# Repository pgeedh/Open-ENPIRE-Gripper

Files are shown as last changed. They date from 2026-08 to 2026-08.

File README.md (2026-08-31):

# Open-ENPIRE-Gripper-NVIDIA

<div align="center">






### Universal Compliant Gripper (UCG) Adapters for Robot Learning & Physical AI

<br>

<table align="center" border="0">
  <tr>
    <th align="center" width="50%">NVIDIA GEAR ENPIRE Research Video</th>
    <th align="center" width="50%">Robotiq Hand-E Physical Adapter</th>
  </tr>
  <tr>
    <td align="center" valign="top">
      <a href="https://research.nvidia.com/labs/gear/enpire/">
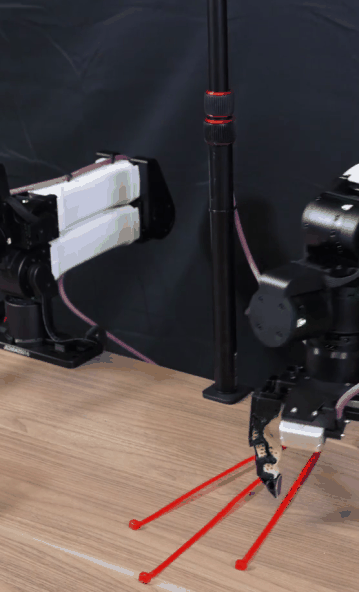
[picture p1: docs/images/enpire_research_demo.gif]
NVIDIA GEAR ENPIRE Autonomous Manipulation
        
      </a>
    </td>
    <td align="center" valign="top">
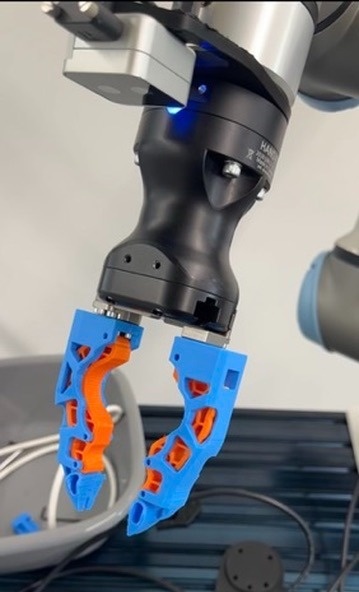
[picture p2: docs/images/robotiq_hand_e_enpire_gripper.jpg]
Robotiq Hand-E ENPIRE Gripper
      
    </td>
  </tr>
</table>

</div>

---

## Purpose & Mission

### Why This Project Exists
In physical AI manipulation research, grasping reliability is fundamentally determined by hardware contact mechanics, including surface friction, passive compliance, and tactile geometry. When NVIDIA's GEAR lab published **ENPIRE** (*Agentic Robot Policy Self-Improvement in the Real World*), co-led by **Dr. Jim Fan** ([@DrJimFan](https://twitter.com/DrJimFan)) and **Dr. Yuke Zhu**, the physical robot achieved remarkable grasping reliability using a custom-engineered 3D-printable finger designed by **Wenli Xiao** (CMU & NVIDIA GEAR) for the **I2RT YAM** robotic arm.

<table align="center" border="0">
  <tr>
    <th align="center" width="50%">Original NVIDIA ENPIRE (I2RT YAM)</th>
    <th align="center" width="50%">Generalist AI (Bimanual Manipulation)</th>
  </tr>
  <tr>
    <td align="center" valign="top">
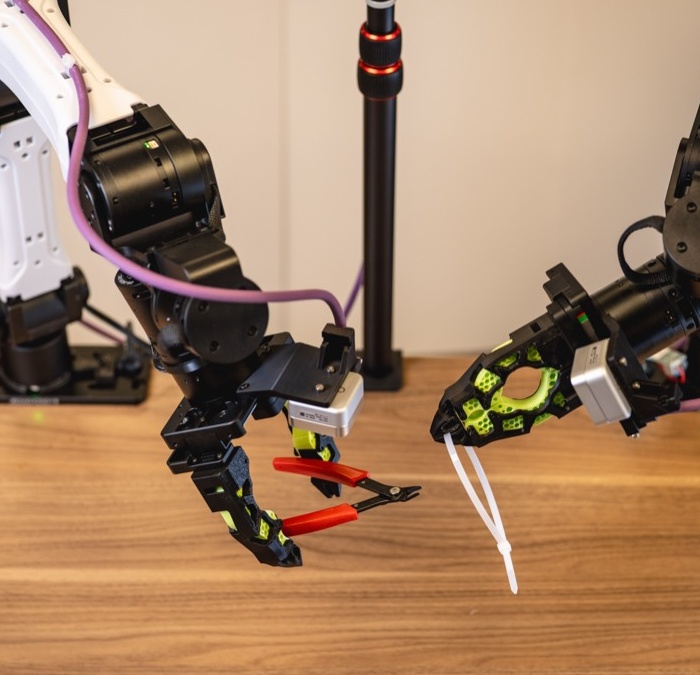
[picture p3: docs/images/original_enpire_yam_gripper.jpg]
Original NVIDIA ENPIRE I2RT YAM Gripper
      
    </td>
    <td align="center" valign="top">
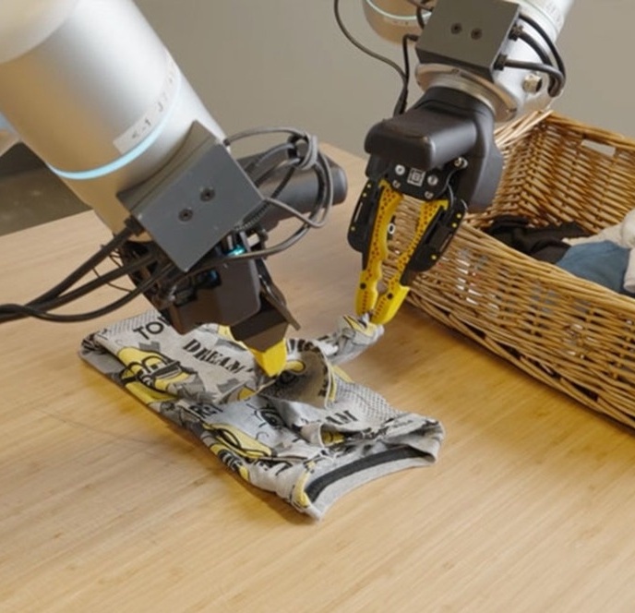
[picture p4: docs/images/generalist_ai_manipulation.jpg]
Generalist AI Bimanual Manipulation
      
    </td>
  </tr>
</table>

However, the I2RT YAM is a specialized research arm that very few universities, startups, independent makers, or robotics labs own.

### The Rise of Universal Compliant Grippers (UCG) in Physical AI
Across the frontier robotics industry, leading physical AI companies and research teams (including **[Generalist AI](https://generalistai.com/blog/research-preview)**, **[Physical Intelligence (Pi)](https://twitter.com/Physical_Int)**, **[Figure AI](https://twitter.com/Figure_robot)**, **[1X Technologies](https://twitter.com/1x_tech)**, **[Skild AI](https://twitter.com/Skild_AI)**, **[Tesla Optimus](https://twitter.com/Tesla_Optimus)**, **[AgileX Robotics](https://twitter.com/AgilexRobotics)**, and **[Toyota Research Institute (TRI)](https://www.tri.global/)**) are converging on a shared thesis: **deploying general-purpose physical AI requires versatile, compliant, high-friction parallel fingertips that can handle diverse, delicate, and high-force interactions without tool-changers**.

We refer to this design paradigm as the **Universal Compliant Gripper (UCG)**.  
*(Note: UCG is not an official industry acronym, but rather our term to describe this class of cross-platform, passively compliant, high-friction parallel hardware).*

### Empowering Modern Robot Learning: $\pi_0$, GR00T, Diffusion Policy, & ACT
State-of-the-art robot learning policies and foundation models require hardware that can absorb physical uncertainty:
* **$\pi_0$ (Pi-Zero by Physical Intelligence)**: Flow-matching / diffusion generalist physical AI model requiring robust non-slip tactile dynamics across complex multi-task domains.
* **GR00T (NVIDIA Generalist Robot 00T)**: Multimodal foundation model driving humanoid and bimanual dexterous manipulation.
* **Diffusion Policy (DP / Chi et al.)**: Visuomotor action diffusion executing high-frequency continuous action trajectories.
* **ACT (Action Chunking with Transformers / Zhao et al.)**: High-frequency bimanual imitation learning powering ALOHA and tabletop learning rigs.
* **OpenVLA, Octo, RT-1 & RT-2**: Vision-Language-Action models mapping tokens to spatial end-effector displacements.

When training these policies, robots encounter an expansive distribution of physical objects: folding delicate fabrics, tensioning flexible zip-ties, sorting thin fasteners, handling micro-pins, and seating rigid PCBs.

The core aim of this project is to deliver a **Universal Compliant Gripper (UCG) finger architecture versatile enough to master this broad spectrum of manipulation tasks** to **enhance the capabilities of existing robot hardware** and **democratize frontier physical AI for everyone**.

In the open-source community, researchers and builders train policies across diverse robotic arms:
* **Robotiq Hand-E**: Precision electric parallel gripper for industrial and research cobots.
* **Robotiq 2F-85 & 2F-140**: High-payload adaptive parallel grippers for Universal Robots, Kinova, and AUBO.
* **Open Arm**: Accessible open-source robotics platform.
* **I2RT YAM**: Foundational research platform from NVIDIA GEAR ENPIRE.
* **ALOHA / Mobile ALOHA**: Stanford/Trossen bimanual imitation learning standard.
* **AgileX (Piper)**: Lightweight 6-DoF bimanual research arms.
* **Seeed Studio reBot**: Low-cost edge AI vision-language-action (VLA) testbed.
* **Franka Emika Panda / FR3**: 7-DoF contact-physics research standard.
* **ARX5**: Bimanual mobile manipulation arms.

### Mission: Democratizing Frontier Gripper Design
> **Hardware breakthroughs in robotics should not be locked to a single proprietary arm.**
> 
> The mission of **Open-ENPIRE-Gripper-NVIDIA** is to bridge the gap between frontier physical AI research and the global robotics community:
> 1. **Universal Accessibility**: Translate the proven high-friction, compliant contact profile into 3D-printable STL adapters for popular robot arms. All printable models can be found in the [`grippers-stl/`](grippers-stl/) folder.
> 2. **Physical AI for Everyone**: Enable anyone with a standard 3D printer to achieve frontier-grade contact mechanics on their existing robot without purchasing expensive custom end-effectors.
> 3. **Community-Driven Standardization**: Establish this geometry as an open-source standard across all parallel-jaw robotic grippers, starting with our physical adaptations for **Robotiq Hand-E**, **Robotiq 2F-140**, **Open Arm**, and **I2RT YAM**.

*Original MakerWorld Project: [Gripper Finger for Robot Arm](https://makerworld.com/en/models/2984746-gripper-finger-for-robot-arm) / [Profile #3349177](https://makerworld.com/en/models/2984746-gripper-finger-for-robot-arm#profileId-3349177) by Wenli Xiao.*

---

## 🎨 3D STL Model Visual Gallery

<table align="center" border="0">
  <tr>
    <th align="center" width="25%">Robotiq Hand-E UCG</th>
    <th align="center" width="25%">Robotiq 2F-140 UCG</th>
    <th align="center" width="25%">Open Arm UCG</th>
    <th align="center" width="25%">I2RT YAM Baseline</th>
  </tr>
  <tr>
    <td align="center" valign="top">
      <a href="grippers-stl/hand_e_stl/">
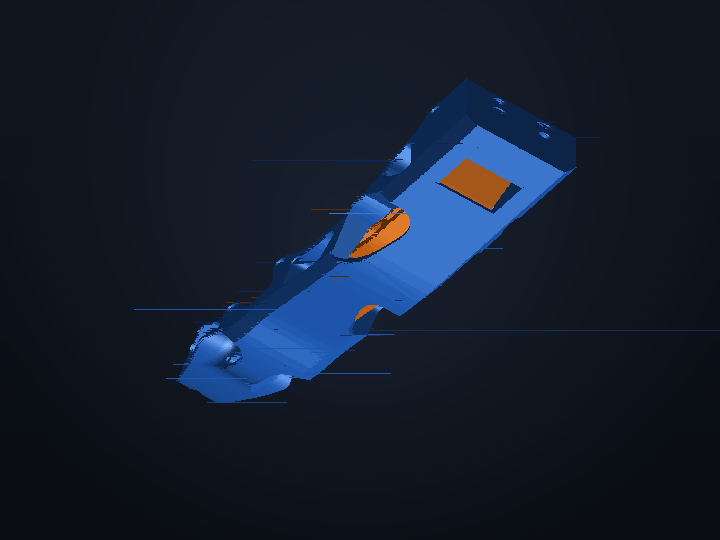
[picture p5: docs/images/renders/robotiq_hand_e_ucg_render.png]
Robotiq Hand-E UCG Render
        
      </a>
    </td>
    <td align="center" valign="top">
      <a href="grippers-stl/robotiq_2f85_2f140_stl/">
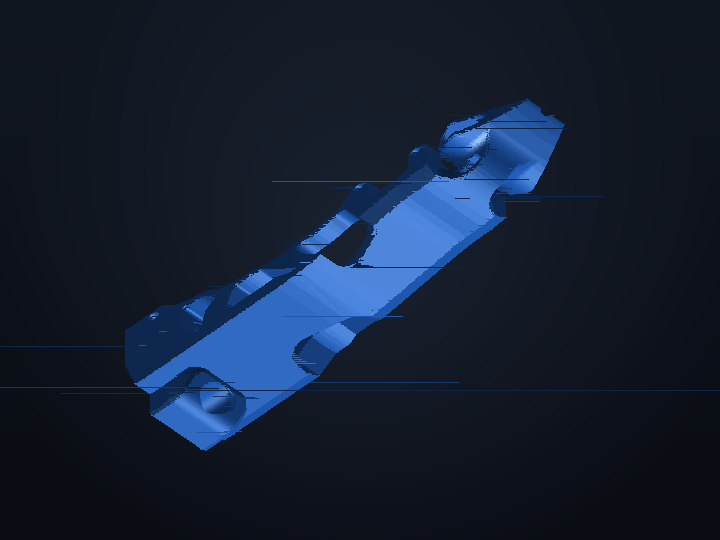
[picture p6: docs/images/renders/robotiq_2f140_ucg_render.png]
Robotiq 2F-140 UCG Render
        
      </a>
    </td>
    <td align="center" valign="top">
      <a href="grippers-stl/open_arm_stl/">
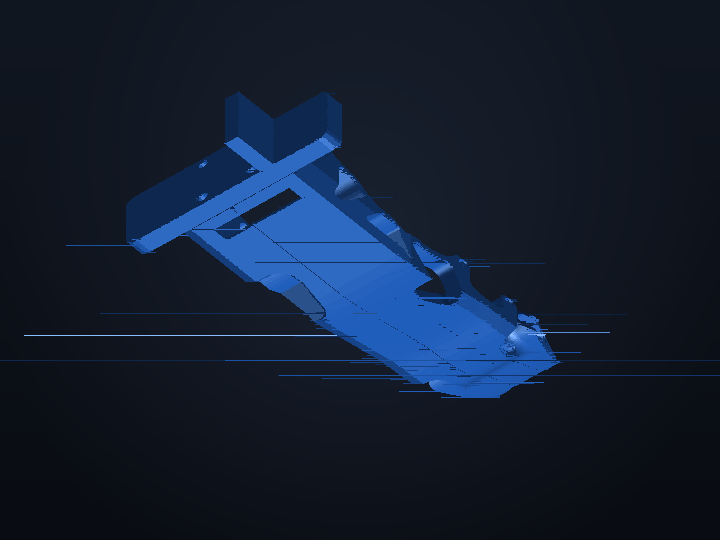
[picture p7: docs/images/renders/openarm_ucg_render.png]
Open Arm UCG Render
        
      </a>
    </td>
    <td align="center" valign="top">
      <a href="grippers-stl/enpire_i2rt_yam_stl/">
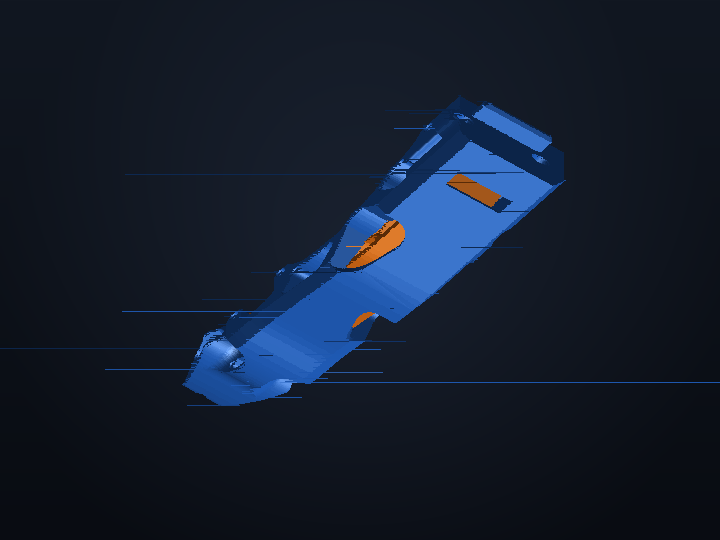
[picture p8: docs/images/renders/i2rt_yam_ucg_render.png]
I2RT YAM Baseline Render
        
      </a>
    </td>
  </tr>
  <tr>
    <td align="center"><strong>Robotiq Hand-E</strong></td>
    <td align="center"><strong>Robotiq 2F-140 / 2F-85</strong></td>
    <td align="center"><strong>Open Arm</strong></td>
    <td align="center"><strong>I2RT YAM Baseline</strong></td>
  </tr>
</table>

---

## Robot Compatibility Matrix

> 💡 **3D Printable Files**: All gripper STL models for supported robotic arms are available in the [`grippers-stl/`](grippers-stl/) directory.

| Robot Platform | Arm Type / Gripper Interface | Status | Target STL Folder |
| :--- | :--- | :---: | :--- |
| [**Robotiq Hand-E**](https://robotiq.com/products/hand-e-adaptive-robot-gripper) | Precision Electric Parallel Gripper | **Available** | [`grippers-stl/hand_e_stl/`](grippers-stl/hand_e_stl/) |
| [**Robotiq 2F-85 / 2F-140**](https://robotiq.com/products/2f85-140-adaptive-robot-gripper) | 2× M4 Bracket Mount (10 mm spacing) | **Available** | [`grippers-stl/robotiq_2f85_2f140_stl/`](grippers-stl/robotiq_2f85_2f140_stl/) |
| **Open Arm** | Modular Open-Source Parallel Mount | **Available** | [`grippers-stl/open_arm_stl/`](grippers-stl/open_arm_stl/) |
| **I2RT YAM** | Native Dual M3 Clamp (Wenli Xiao Baseline) | **Available** | [`grippers-stl/enpire_i2rt_yam_stl/`](grippers-stl/enpire_i2rt_yam_stl/) |
| **ALOHA / Mobile ALOHA** | ViperX Parallel Jaw Carriage | *In Progress* | [`grippers-stl/aloha_stl/`](grippers-stl/aloha_stl/) |
| **AgileX (Piper)** | Dual Pin + M3 Fastener Slider | *In Progress* | [`grippers-stl/agilex_stl/`](grippers-stl/agilex_stl/) |
| **Seeed Studio reBot** | AI Arm Parallel Gripper Slider | *In Progress* | [`grippers-stl/seeed_rebot_stl/`](grippers-stl/seeed_rebot_stl/) |
| **Franka Panda / FR3** | Quick-Mount Dovetail / M4 Slider | *In Progress* | [`grippers-stl/franka_panda_stl/`](grippers-stl/franka_panda_stl/) |
| **ARX5** | Direct Dual Lug M3 Pattern | *In Progress* | [`grippers-stl/arx5_stl/`](grippers-stl/arx5_stl/) |
| **ISO 9409-1 (UR / xArm)** | Universal Tool Flange Adapter Plates | *In Progress* | [`grippers-stl/iso_flange_adapters_stl/`](grippers-stl/iso_flange_adapters_stl/) |

*Status: Available (Production-ready STL models available) | In Progress (Community Contributions Welcome)*

---

## 📦 Production STL Model Catalog

| Target Gripper Platform | Model Filename | Role & Material | Bounding Box Dimensions |
| :--- | :--- | :--- | :--- |
| **Robotiq Hand-E** | [`Robotiq_UCG_Hard_Hand_E.stl`](grippers-stl/hand_e_stl/Robotiq_UCG_Hard_Hand_E.stl) | Rigid Structural Frame (PETG-CF / PA-CF) | 28.9 × 109.5 × 32.6 mm |
| **Robotiq Hand-E** | [`Robotiq_UCG_Soft_Hand_E.stl`](grippers-stl/hand_e_stl/Robotiq_UCG_Soft_Hand_E.stl) | Compliant Grip Core (TPU 85A/95A) | 15.0 × 81.0 × 29.8 mm |
| **Robotiq 2F-140 / 2F-85** | [`Robotiq_2F-140-UCG_Hard.stl`](grippers-stl/robotiq_2f85_2f140_stl/Robotiq_2F-140-UCG_Hard.stl) | High-Strength Jaw Adapter (PETG-CF / PA-CF) | 28.9 × 107.4 × 45.4 mm |
| **Robotiq 2F-140 / 2F-85** | [`Robotiq_2F-140-UCG_soft.stl`](grippers-stl/robotiq_2f85_2f140_stl/Robotiq_2F-140-UCG_soft.stl) | Compliant Grip Core (TPU 85A/95A) | 15.0 × 81.0 × 29.8 mm |
| **Open Arm** | [`OpenArm_UCG_left_hard.stl`](grippers-stl/open_arm_stl/OpenArm_UCG_left_hard.stl) | Rigid Left Jaw Mount (PETG-CF / PA-CF) | 121.7 × 61.0 × 32.6 mm |
| **I2RT YAM** | [`i2rt_UCG_Hard.stl`](grippers-stl/enpire_i2rt_yam_stl/i2rt_UCG_Hard.stl) | Baseline Rigid Frame (PETG-CF / PA-CF) | 31.6 × 114.9 × 32.6 mm |
| **I2RT YAM** | [`I2RT_UCG_Soft.stl`](grippers-stl/enpire_i2rt_yam_stl/I2RT_UCG_Soft.stl) | Baseline Compliant Core (TPU 85A/95A) | 15.0 × 81.0 × 29.8 mm |

---

## 3D Printing Specifications & Tested Slicer Profile

All parts shown were printed and verified on a **Bambu Lab P1S** using **Bambu Studio / OrcaSlicer**.

### 1. Infill Geometry & Wall Parameters (Bambu Lab P1S)
* **Infill Pattern**: **Gyroid** is strongly recommended. Gyroid provides uniform, isotropic load resistance in all axes ($X, Y, Z$), preventing internal shear fracture when the gripper applies peak clamping torque.
* **Infill Density**:
  * **50% – 60% Gyroid** for the rigid structural frame.
  * **30% – 40% Gyroid** for the compliant grip insert (provides elastic compliance to conform around delicate components).
* **Wall Loops / Perimeters**: **5 to 6 walls** (ensures solid M3/M4 mounting hole walls and maximum beam bending stiffness).
* **Top & Bottom Shells**: **5 solid layers** for zero flex at fastener interfaces.

### 2. Support Configuration (Bambu Studio / OrcaSlicer)
* **Support Type**: **Tree (Auto)** / Tree Slim.
* **Threshold Angle**: **35° – 45°**.
* **Top Z Distance**: **0.20 mm** (clean surface separation with zero scarring).
* **Bottom Z Distance**: **0.20 mm**.
* **Support Wall Loops**: **1**.
* **Support Infill**: 15% Grid / Tree Branch.

### 3. Slicer Parameter Table

| Parameter | Rigid Frame (PETG-CF / PA-CF) | Compliant Grip Core (TPU 85A/95A) |
| :--- | :--- | :--- |
| **Tested Machine** | **Bambu Lab P1S** | **Bambu Lab P1S** |
| **Layer Height** | **0.16 mm** (Optimal for screw counterbores) | **0.16 mm – 0.20 mm** |
| **Wall Loops** | **5 – 6 walls** (Critical for strength) | **4 walls** |
| **Infill Pattern** | **Gyroid (50% – 60%)** | **Gyroid (30% – 40%)** |
| **Nozzle Temp** | 255°C (PETG-CF) / 285°C (PA-CF) | 225°C – 235°C (TPU) |
| **Bed Temp** | 70°C – 80°C (Textured PEI Plate) | 45°C – 55°C (Engineering Plate) |
| **Print Speed** | 80 – 160 mm/s | 20 – 35 mm/s (Slow for TPU flow) |
| **Supports** | Tree Auto (40° threshold, 0.2mm Top-Z) | None needed |

### 4. Hardware Assembly & Fastener Notes
* **Heat-Set Brass Inserts**: Press M3/M4 threaded inserts flush into mounting pockets using a soldering iron set to **230°C** for PETG/PLA or **275°C** for PA-CF.
* **Fasteners**: Use ISO 4762 Grade 12.9 M3/M4 socket head cap screws with medium blue threadlocker (Loctite 243) to prevent vibration-induced loosening.

---

## URDF Simulation Models & STL Automation

We provide an automated script in `scripts/generate_urdf_from_stl.py` that parses any pair of finger STL files from [`grippers-stl/`](grippers-stl/), calculates center-of-mass, inertia, scales from millimeters to meters, and outputs a physics-ready **URDF** for **NVIDIA Isaac Sim, MuJoCo, PyBullet, and ROS 2** (runs with zero dependencies using standard Python 3):

```bash
# Example 1: Generate URDF for Robotiq Hand-E
python3 scripts/generate_urdf_from_stl.py \
  --name hand_e_enpire_gripper \
  --left_stl grippers-stl/hand_e_stl/Robotiq_UCG_Hard_Hand_E.stl \
  --right_stl grippers-stl/hand_e_stl/Robotiq_UCG_Hard_Hand_E.stl \
  --stroke_mm 50.0 \
  --force_n 130.0 \
  --out hand_e_enpire_gripper.urdf

# Example 2: Generate URDF for Robotiq 2F-140
python3 scripts/generate_urdf_from_stl.py \
  --name robotiq_2f140_enpire_gripper \
  --left_stl grippers-stl/robotiq_2f85_2f140_stl/Robotiq_2F-140-UCG_Hard.stl \
  --right_stl grippers-stl/robotiq_2f85_2f140_stl/Robotiq_2F-140-UCG_Hard.stl \
  --stroke_mm 140.0 \
  --force_n 235.0 \
  --out robotiq_2f140_enpire_gripper.urdf

# Example 3: Generate URDF for I2RT YAM
python3 scripts/generate_urdf_from_stl.py \
  --name enpire_yam_gripper \
  --left_stl grippers-stl/enpire_i2rt_yam_stl/i2rt_UCG_Hard.stl \
  --right_stl grippers-stl/enpire_i2rt_yam_stl/i2rt_UCG_Hard.stl \
  --stroke_mm 50.0 \
  --force_n 100.0 \
  --out enpire_yam_gripper.urdf
```

---

## Rules for Contributing

1. **Watertight Mesh**: Export binary STL files with zero non-manifold edges. Verify using:
   ```bash
   python3 scripts/validate_mesh.py
   ```
2. **Standard Orientation**: Coordinate frames must align ($+Z$ finger length, $+Y$ inward contact face). Export oriented flat on its side.
3. **Physical Test Print Required**: You must physically print the part and verify full stroke closure without binding before submitting a PR.
4. **PR Checklist**: Attach clear photos of the 3D-printed part installed on your robot arm and list your slicer settings.

*See [CONTRIBUTING.md](CONTRIBUTING.md) for full guidelines.*

---

## Citation & Attribution

If you use this gripper design or its multi-arm adapters in your research, please cite both the foundational ENPIRE paper and this open-source hardware project:

### 1. Foundational ENPIRE Research Paper
```bibtex
@article{xiao2024enpire,
  title={ENPIRE: Agentic Robot Policy Self-Improvement in the Real World},
  author={Xiao, Wenli and Fan, Linxi and Zhu, Yuke and GEAR Lab and Collaborators},
  journal={arXiv preprint},
  year={2024}
}
```

### 2. Open-ENPIRE-Gripper-NVIDIA Repository & Design Adaptation
```bibtex
@misc{open_enpire_gripper_2026,
  title={Open-ENPIRE-Gripper-NVIDIA: Universal Compliant Gripper (UCG) Adapters for Robot Learning and Physical AI},
  author={Geedh, Pruthvi Omkar and Open Source Robotics Community},
  howpublished={\url{https://github.com/pgeedh/Open-ENPIRE-Gripper-nvidia}},
  year={2026}
}
```

*Foundational fingertip design by **Wenli Xiao** (CMU / NVIDIA GEAR) via [MakerWorld #3349177](https://makerworld.com/en/models/2984746-gripper-finger-for-robot-arm). Research led by **Dr. Jim Fan** ([@DrJimFan](https://twitter.com/DrJimFan)) & **Dr. Yuke Zhu**.*

---

## License

Licensed under the [Apache License, Version 2.0](LICENSE).

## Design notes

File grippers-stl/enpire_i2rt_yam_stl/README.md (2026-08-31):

<div align="center">

# I2RT YAM Baseline ENPIRE Gripper Models

### Foundational 3D-Printable Compliant Finger Architecture by Wenli Xiao (CMU / NVIDIA GEAR)

<br>

<table align="center" border="0">
  <tr>
    <th align="center" width="50%">Original I2RT YAM Physical Arm</th>
    <th align="center" width="50%">ENPIRE Dual-Material 3D Model Render</th>
  </tr>
  <tr>
    <td align="center" valign="top">
      Original NVIDIA ENPIRE I2RT YAM Gripper
    </td>
    <td align="center" valign="top">
      I2RT YAM Dual-Material ENPIRE UCG 3D CAD Render
    </td>
  </tr>
</table>
<br>
<em>Left: Original ENPIRE compliant finger on the I2RT YAM arm (NVIDIA GEAR Lab). Right: 3D CAD model rendering of rigid frame (Blue) with compliant TPU core (Orange).</em>

</div>

---

## Overview

This directory houses the baseline documentation and reference models for the foundational **I2RT YAM** robotic arm gripper fingers originally created by **Wenli Xiao** (CMU & NVIDIA GEAR Lab) for the **NVIDIA ENPIRE** project (*Agentic Robot Policy Self-Improvement in the Real World*).

---

## 🔗 Official MakerWorld Sources
* 🌐 **MakerWorld Model Page**: [Gripper Finger for Robot Arm (Model #2984746)](https://makerworld.com/en/models/2984746-gripper-finger-for-robot-arm)
* 👤 **Designer Profile**: [Wenli Xiao (Profile #3349177)](https://makerworld.com/en/models/2984746-gripper-finger-for-robot-arm#profileId-3349177)
* 📄 **Research Paper**: [ENPIRE: Agentic Robot Policy Self-Improvement in the Real World](https://research.nvidia.com/labs/gear/enpire/)

---

## 📦 Production-Ready STL Models

* **`i2rt_UCG_Hard.stl`** — Primary rigid structural frame adapter for I2RT YAM arms (print in PETG-CF / PA-CF / PLA-CF).
* **`I2RT_UCG_Soft.stl`** — Compliant high-friction tactile grip insert (print in TPU 85A / TPU 95A).

---

## 📐 Mechanical Specifications (I2RT YAM Platform)

| Parameter | Specification |
| :--- | :--- |
| **Robot Arm Platform** | **I2RT YAM** Research Arm |
| **Mounting Interface** | Dual M3 clamping bolt pattern |
| **Finger Style** | Compliant high-friction curved parallel finger (Dual-material) |
| **Frame Dimensions (Hard)** | 31.6 mm × 114.9 mm × 32.6 mm |
| **Insert Dimensions (Soft)** | 15.0 mm × 81.0 mm × 29.8 mm |
| **Materials** | Dual-material: Rigid skeleton (PETG/PA-CF) + Compliant core (TPU 85A/95A) |
| **Primary Tasks** | High-precision pin insertion, zip-tie manipulation, GPU seating, USB plug insertion |

---

## 🖨️ Recommended 3D Printing Settings (Bambu Lab P1S)

* **Body (Rigid Frame `i2rt_UCG_Hard.stl`)**: PETG-CF / PA-CF, 0.16 mm layer height, 5–6 walls, 50% Gyroid infill
* **Grip Pad (Compliant Core `I2RT_UCG_Soft.stl`)**: TPU 85A or TPU 95A, 0.16 mm layer height, 4 walls, 30% Gyroid infill
* **Supports**: Tree (Auto), 40° threshold angle, 0.20 mm Top Z distance

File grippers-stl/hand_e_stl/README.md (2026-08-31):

<div align="center">

<a href="https://robotiq.com/products/hand-e-adaptive-robot-gripper">
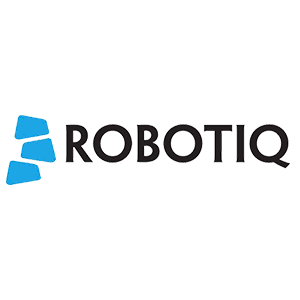
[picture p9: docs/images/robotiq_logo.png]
Robotiq Logo
  
</a>

# Robotiq Hand-E Universal Compliant Gripper (UCG)

### Transforming the Standard Industrial Robotiq Hand-E into a Frontier High-Friction Compliant Gripper for Robot Learning & Physical AI

<br>

<table align="center" border="0">
  <tr>
    <th align="center" width="33%">Standard OEM Robotiq Hand-E</th>
    <th align="center" width="33%">Physical Hand-E + ENPIRE Fingers</th>
    <th align="center" width="33%">3D Dual-Material CAD Render</th>
  </tr>
  <tr>
    <td align="center" valign="top">
      <a href="https://robotiq.com/products/hand-e-adaptive-robot-gripper">
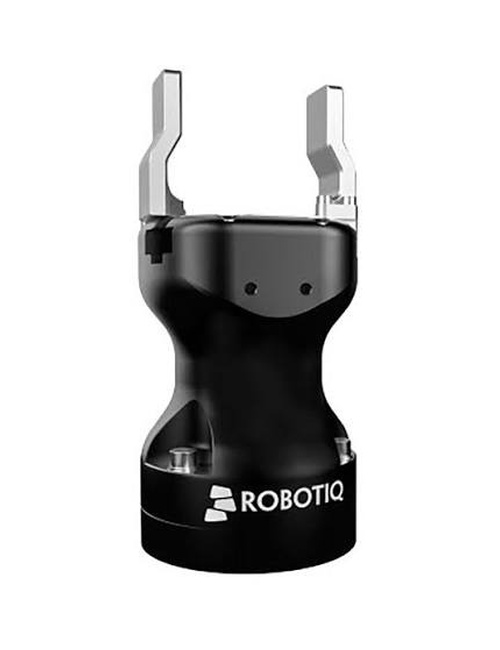
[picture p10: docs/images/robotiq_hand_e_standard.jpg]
Standard OEM Robotiq Hand-E
        
      </a>
    </td>
    <td align="center" valign="top">
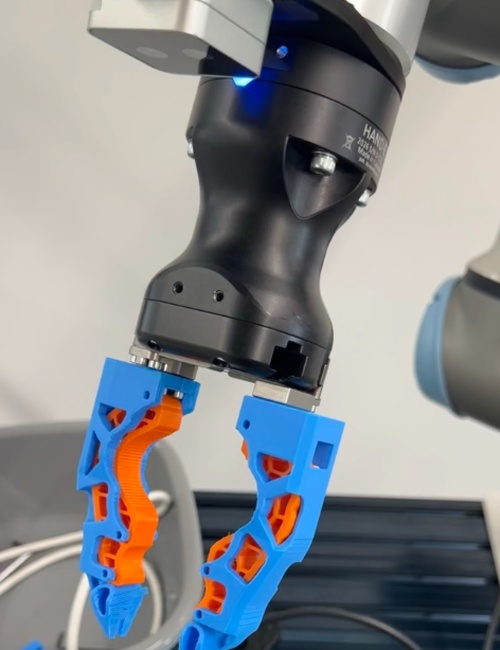
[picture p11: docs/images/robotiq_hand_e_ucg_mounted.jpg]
Robotiq Hand-E with ENPIRE UCG Fingers
      
    </td>
    <td align="center" valign="top">
      Robotiq Hand-E UCG Dual-Material 3D CAD Render
    </td>
  </tr>
</table>

</div>

---

## 🔗 Official Hardware Reference
* 🌐 **Official Product Page**: [Robotiq Hand-E Adaptive Robot Gripper](https://robotiq.com/products/hand-e-adaptive-robot-gripper)
* 📖 **Robotiq Support & Manuals**: [support.robotiq.com](https://support.robotiq.com)

---

## 📦 Production-Ready STL Files

This directory contains the production-ready **3D-printable binary STL files** for mounting the ENPIRE Universal Compliant Gripper (UCG) fingertip geometry directly onto the **Robotiq Hand-E** electric parallel gripper:

* **`Robotiq_UCG_Hard_Hand_E.stl`** — Primary rigid structural skeleton adapter (print in PETG-CF / PA-CF / PLA-CF)
* **`Robotiq_UCG_Soft_Hand_E.stl`** — Compliant high-friction tactile grip insert (print in TPU 85A / TPU 95A)

---

## 📐 Mechanical Specifications

| Parameter | Specification |
| :--- | :--- |
| **Gripper Platform** | [**Robotiq Hand-E**](https://robotiq.com/products/hand-e-adaptive-robot-gripper) (Linear Parallel Stroke) |
| **Finger Design Paradigm** | **Universal Compliant Gripper (UCG)** |
| **Mounting Fasteners** | 2× M4 / M3 socket head cap screws per finger |
| **Fastener Spacing** | Standard Robotiq 10 mm PCD pattern |
| **Frame Dimensions (Hard)** | 28.9 mm × 109.5 mm × 32.6 mm |
| **Insert Dimensions (Soft)** | 15.0 mm × 81.0 mm × 29.8 mm |
| **Linear Stroke** | 50.0 mm parallel travel |
| **Programmable Clamping Force** | 20 N to 130 N |
| **Contact Surface** | Dual-material rigid backbone with ribbed compliant high-friction core ($\mu > 0.8$) |

---

## 🖨️ Tested 3D Printing Profile (Bambu Lab P1S)

* **Materials**:
  * **Outer Rigid Backbone (`Robotiq_UCG_Hard_Hand_E.stl`)**: **PETG-CF**, **PLA-CF**, or **PA12-CF (Nylon-CF)** (Blue)
  * **Compliant Friction Core (`Robotiq_UCG_Soft_Hand_E.stl`)**: **TPU 85A** or **TPU 95A** (Orange)
* **Layer Height**: **0.16 mm** (Optimal for screw counterbores and tooth engagement)
* **Wall Loops / Perimeters**: **5 to 6 walls** (Critical for bolt clamp strength)
* **Infill Pattern & Density**: **50% – 60% Gyroid** (Rigid frame) / **30% – 40% Gyroid** (TPU core)
* **Support Configuration**: Tree (Auto), 40° threshold, **0.20 mm Top Z distance**

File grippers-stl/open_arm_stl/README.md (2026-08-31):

<div align="center">

# Open Arm Universal Compliant Gripper (UCG) STL Models

### 3D-Printable High-Friction Compliant Gripper Adapters for Open Arm Platforms

<br>

Open Arm ENPIRE UCG Finger 3D CAD Render
<br>
<em>High-rigidity Open Arm Universal Compliant Gripper (UCG) left jaw adapter (OpenArm_UCG_left_hard.stl).</em>

</div>

---

## Overview

This directory contains the production-ready 3D-printable binary STL files for mounting the **Universal Compliant Gripper (UCG)** geometry directly onto **Open Arm** robotic manipulators. 

By translating the high-friction, compliant contact profile into the Open Arm platform, researchers and builders can achieve frontier-grade physical AI grasping reliability on accessible open-source robotics hardware.

---

## 📦 Production-Ready STL Models

* **`OpenArm_UCG_left_hard.stl`** — Primary rigid structural jaw adapter for Open Arm parallel sliders (print in PETG-CF / PA-CF / PLA-CF).

---

## 📐 Mechanical Specifications

| Parameter | Specification |
| :--- | :--- |
| **Robot Platform** | **Open Arm** Robotic Manipulator |
| **Gripper Architecture** | **Universal Compliant Gripper (UCG)** Parallel Jaw |
| **Mounting Interface** | Modular parallel jaw slider mount |
| **Overall Length ($+X$)** | 121.7 mm |
| **Height ($+Y$)** | 61.0 mm |
| **Width ($+Z$)** | 32.6 mm |
| **Estimated Stroke** | 60.0 mm – 70.0 mm |
| **Primary Material** | **PETG-CF** / **PA12-CF** (Rigid Backbone) |
| **Best Applications** | Open-source robotics education, accessible physical AI manipulation, imitation learning |

---

## 🖨️ Tested 3D Printing Profile (Bambu Lab P1S)

All models are verified for dimensional accuracy and structural rigidity:

* **Filament**: **PETG-CF**, **PA12-CF (Nylon-CF)**, or **PLA-CF**
* **Layer Height**: **0.16 mm** (Optimal for mounting tolerances and screw counterbores)
* **Wall Loops / Perimeters**: **5 to 6 walls** (Critical for beam stiffness under clamping load)
* **Infill Pattern & Density**: **50% – 60% Gyroid** (Isotropic shear load resistance)
* **Support Configuration**: Tree (Auto), 40° threshold angle, **0.20 mm Top Z distance**

---

## 🤝 Community Contributions

> 💡 **Have an additional variation?** If you have designed a complementary right jaw, soft TPU friction insert, or alternate slider bracket for Open Arm, we would love your contribution!
>
> Please submit a **[Pull Request](https://github.com/pgeedh/Open-ENPIRE-Gripper-nvidia/pulls)** following our [Rules for Contributing](../../CONTRIBUTING.md).

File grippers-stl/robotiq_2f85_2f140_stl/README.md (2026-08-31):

<div align="center">

# Robotiq 2F-85 / 2F-140 Universal Compliant Gripper (UCG) STL Models

### Transforming Heavy-Duty Robotiq 2-Finger Adaptive Grippers for Physical AI Manipulation & Policy Self-Improvement

<br>

Robotiq 2F-140 ENPIRE UCG Finger 3D CAD Render
<br>
<em>Heavy-duty Robotiq 2F-140 Universal Compliant Gripper (UCG) finger adapter (Robotiq_2F-140-UCG_Hard.stl).</em>

</div>

---

## Overview

This directory contains production-ready 3D-printable binary STL files for mounting the **Universal Compliant Gripper (UCG)** geometry onto **Robotiq 2F-85** and **Robotiq 2F-140** adaptive robot grippers.

The Robotiq 2F series is one of the most widely deployed industrial parallel end-effectors on Universal Robots (UR3e/UR5e/UR10e/UR16e), Kinova, and AUBO arms. Upgrading the standard rigid aluminum fingers to the ENPIRE compliant high-friction profile enables reliable non-slip grasping across challenging objects (micro-pins, flexible zip-ties, PCB connectors, cables, and delicate glassware) without dropping parts or requiring complex force-torque feedback loops.

---

## 🔗 Official Hardware References
* 🌐 **Official Product Page**: [Robotiq 2F-85 & 2F-140 Adaptive Robot Grippers](https://robotiq.com/products/2f85-140-adaptive-robot-gripper)
* 📖 **Robotiq Documentation**: [support.robotiq.com](https://support.robotiq.com)

---

## 📦 Production-Ready STL Models

* **`Robotiq_2F-140-UCG_Hard.stl`** — High-strength rigid structural adapter finger for Robotiq 2F-140 (and 2F-85 bracket interfaces), optimized for high clamping forces (up to 235 N).
* **`Robotiq_2F-140-UCG_soft.stl`** — Compliant high-friction tactile grip insert (print in TPU 85A / TPU 95A).

---

## 📐 Mechanical Specifications

| Parameter | Specification |
| :--- | :--- |
| **Gripper Models** | [**Robotiq 2F-140**](https://robotiq.com/products/2f85-140-adaptive-robot-gripper) (140mm stroke) / **Robotiq 2F-85** (85mm stroke) |
| **Finger Design Paradigm** | **Universal Compliant Gripper (UCG)** High-Friction Parallel Jaw |
| **Mounting Interface** | 2× M4 socket head cap screws (standard 10 mm center spacing) |
| **Overall Length ($+Y$)** | 107.4 mm |
| **Base Width ($+X$)** | 28.9 mm |
| **Depth ($+Z$)** | 45.4 mm |
| **Linear Stroke Range** | 85.0 mm (2F-85) to 140.0 mm (2F-140) |
| **Maximum Grip Force** | Up to 235 N |
| **Materials** | Dual-material: Rigid skeleton (PETG/PA-CF) + Compliant core (TPU 85A/95A) |
| **Best Applications** | Industrial pick-and-place, machine tending, high-payload robot learning, bimanual assembly |

---

## 🖨️ Tested 3D Printing Profile (Bambu Lab P1S)

* **Body (Rigid Frame `Robotiq_2F-140-UCG_Hard.stl`)**:
  * **Filament**: **PETG-CF**, **PA12-CF (Nylon-CF)**, or **PLA-CF**
  * **Layer Height**: **0.16 mm** (Ensures clean M4 counterbore seating and fine tooth detail)
  * **Wall Loops / Perimeters**: **5 to 6 walls** (Critical for bearing 235 N clamping forces)
  * **Infill Pattern & Density**: **50% – 60% Gyroid** (Isotropic stress distribution)
  * **Support Configuration**: Tree (Auto), 40° threshold, **0.20 mm Top Z distance**
* **Grip Pad (Compliant Core `Robotiq_2F-140-UCG_soft.stl`)**:
  * **Filament**: **TPU 85A** or **TPU 95A**
  * **Layer Height**: **0.16 mm – 0.20 mm**
  * **Wall Loops**: **4 walls**
  * **Infill Pattern & Density**: **30% – 40% Gyroid**
  * **Supports**: None needed

---

## 🤝 Community Contributions

> 💡 **Have an additional variation?** If you have designed an extended thin-pinch variant or alternate mounting bracket for Robotiq 2F grippers, feel free to **[submit a Pull Request](https://github.com/pgeedh/Open-ENPIRE-Gripper-nvidia/pulls)** following our [Rules for Contributing](../../CONTRIBUTING.md).

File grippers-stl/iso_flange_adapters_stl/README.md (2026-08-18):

# ISO 9409-1 Flange Adapter STL Models

> 🚧 **Work in Progress**: We are actively developing and test-printing the **ISO 9409-1** tool flange adapter plates (for Universal Robots, xArm, etc.) and will update this folder shortly!
>
> 💡 **Already have a working design?** If you have already designed, 3D-printed, or tested an ISO flange adapter plate for this setup, we would love your contribution! Feel free to **[submit a Pull Request](https://github.com/pgeedh/Open-ENPIRE-Gripper-nvidia/pulls)** to help make this available to the community.
>
> *Please check our [Rules for Contributing](../../CONTRIBUTING.md) for STL formatting, coordinate orientation, and physical verification guidelines.*

---

## Flange Standards Supported
* **ISO 9409-1-50-4-M6**: 50 mm PCD (4× M6 screws), used by Universal Robots (UR3e/5e/10e), UFactory xArm 6/7, Doosan, Elite.
* **ISO 9409-1-31.5-4-M5**: 31.5 mm PCD (4× M5 screws), used by compact cobots.

---

## Target STL Naming
* `iso_9409_1_50_4_m6_plate.stl`
* `iso_9409_1_31_5_4_m5_plate.stl`

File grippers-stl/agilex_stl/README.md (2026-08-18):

# AgileX (Piper) Arm STL Models

> 🚧 **Work in Progress**: We are actively developing and test-printing the ENPIRE finger adapter models for the **AgileX Piper** arm and will update this folder shortly!
>
> 💡 **Already have a working design?** If you have already designed, 3D-printed, or tested an ENPIRE adapter for AgileX Piper, we would love your contribution! Feel free to **[submit a Pull Request](https://github.com/pgeedh/Open-ENPIRE-Gripper-nvidia/pulls)** to help make this available to the community.
>
> *Please check our [Rules for Contributing](../../CONTRIBUTING.md) for STL formatting, coordinate orientation, and physical verification guidelines.*

---

## Gripper Specifications
* **Arm Platform**: AgileX Piper 6-DoF Robotic Arm
* **Gripper Interface**: Dual locating pin + M3 fastener slider mount
* **Stroke**: ~70 mm parallel stroke
* **Grip Force**: ~35 N
* **Best Applications**: Bimanual physical AI manipulation, tabletop research, and teleoperation.

---

## Target STL Naming
* `agilex_piper_enpire_finger_left.stl`
* `agilex_piper_enpire_finger_right.stl`
* `agilex_piper_enpire_finger_v_groove.stl`

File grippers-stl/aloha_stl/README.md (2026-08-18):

# ALOHA & Mobile ALOHA STL Models

> 🚧 **Work in Progress**: We are actively developing and test-printing the ENPIRE finger adapter models for **ALOHA / Mobile ALOHA** bimanual arms and will update this folder shortly!
>
> 💡 **Already have a working design?** If you have already designed, 3D-printed, or tested an ENPIRE adapter for ALOHA, we would love your contribution! Feel free to **[submit a Pull Request](https://github.com/pgeedh/Open-ENPIRE-Gripper-nvidia/pulls)** to help make this available to the community.
>
> *Please check our [Rules for Contributing](../../CONTRIBUTING.md) for STL formatting, coordinate orientation, and physical verification guidelines.*

---

## Gripper Specifications
* **Platform**: ALOHA / Mobile ALOHA / Stanford Bimanual Rig
* **Gripper Interface**: ViperX 300 / 650 parallel jaw carriage
* **Stroke**: 60 mm – 80 mm
* **Grip Force**: ~40 N
* **Best Applications**: Fine bimanual teleoperation, imitation learning, and household/lab manipulation.

---

## Target STL Naming
* `aloha_enpire_finger_left.stl`
* `aloha_enpire_finger_right.stl`
* `aloha_enpire_finger_paddle.stl`

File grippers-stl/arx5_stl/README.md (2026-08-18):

# ARX5 Robot Arm STL Models

> 🚧 **Work in Progress**: We are actively developing and test-printing the ENPIRE finger models for the **ARX5** bimanual robot arm and will update this folder shortly!
>
> 💡 **Already have a working design?** If you have already designed, 3D-printed, or tested an ENPIRE adapter for ARX5, we would love your contribution! Feel free to **[submit a Pull Request](https://github.com/pgeedh/Open-ENPIRE-Gripper-nvidia/pulls)** to help make this available to the community.
>
> *Please check our [Rules for Contributing](../../CONTRIBUTING.md) for STL formatting, coordinate orientation, and physical verification guidelines.*

---

## Gripper Specifications
* **Platform**: ARX5 5-DoF / 6-DoF Arm
* **Gripper Interface**: Direct dual lug M3 fastener pattern
* **Stroke**: ~75 mm
* **Best Applications**: Bimanual mobile manipulation, human-robot interaction.

---

## Target STL Naming
* `arx5_enpire_finger_left.stl`
* `arx5_enpire_finger_right.stl`
* `arx5_enpire_finger_heavy_duty.stl`

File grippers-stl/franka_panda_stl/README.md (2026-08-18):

# Franka Emika Panda / FR3 STL Models

> 🚧 **Work in Progress**: We are actively developing and test-printing the ENPIRE dovetail adapter models for the **Franka Emika Panda / FR3 Hand** and will update this folder shortly!
>
> 💡 **Already have a working design?** If you have already designed, 3D-printed, or tested an ENPIRE adapter for Franka Panda, we would love your contribution! Feel free to **[submit a Pull Request](https://github.com/pgeedh/Open-ENPIRE-Gripper-nvidia/pulls)** to help make this available to the community.
>
> *Please check our [Rules for Contributing](../../CONTRIBUTING.md) for STL formatting, coordinate orientation, and physical verification guidelines.*

---

## Gripper Specifications
* **Platform**: Franka Emika Panda / FR3 7-DoF Robot
* **Gripper Interface**: Quick-mount dovetail / M4 slider bolt
* **Stroke**: 80 mm
* **Grip Force**: Up to 70 N continuous
* **Best Applications**: High-precision contact physics, impedance control research.

---

## Target STL Naming
* `franka_panda_enpire_finger_left.stl`
* `franka_panda_enpire_finger_right.stl`
* `franka_panda_enpire_finger_soft_tip.stl`

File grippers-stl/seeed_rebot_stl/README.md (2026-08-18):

# Seeed Studio reBot STL Models

> 🚧 **Work in Progress**: We are actively developing and test-printing the ENPIRE finger adapter models for the **Seeed Studio reBot** AI arm and will update this folder shortly!
>
> 💡 **Already have a working design?** If you have already designed, 3D-printed, or tested an ENPIRE adapter for Seeed Studio reBot, we would love your contribution! Feel free to **[submit a Pull Request](https://github.com/pgeedh/Open-ENPIRE-Gripper-nvidia/pulls)** to help make this available to the community.
>
> *Please check our [Rules for Contributing](../../CONTRIBUTING.md) for STL formatting, coordinate orientation, and physical verification guidelines.*

---

## Gripper Specifications
* **Platform**: Seeed Studio reBot / reComputer AI Arm
* **Gripper Interface**: Parallel gripper slider
* **Best Applications**: Low-cost physical AI experimentation, edge AI vision-language-action (VLA) models.

---

## Target STL Naming
* `seeed_rebot_enpire_finger_left.stl`
* `seeed_rebot_enpire_finger_right.stl`

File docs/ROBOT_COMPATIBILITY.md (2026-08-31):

# Robot Arm Compatibility Matrix

The **Open-ENPIRE-Gripper-NVIDIA** project aims to establish an open standard across generalist robotic arms, bimanual learning platforms, collaborative cobots, and open-source hardware.

All 3D-printable gripper STL models for supported robot arms are stored in [`grippers-stl/`](../grippers-stl/).

---

## Supported Robot Platforms & Adapter Directories

| Robot Platform | Arm Type / Gripper Interface | Status | Target STL Folder |
| :--- | :--- | :---: | :--- |
| [**Robotiq Hand-E**](https://robotiq.com/products/hand-e-adaptive-robot-gripper) | Precision Electric Parallel Gripper | **Available** | [`grippers-stl/hand_e_stl/`](../grippers-stl/hand_e_stl/) |
| [**Robotiq 2F-85 / 2F-140**](https://robotiq.com/products/2f85-140-adaptive-robot-gripper) | 2× M4 Bracket Mount (10 mm spacing) | **Available** | [`grippers-stl/robotiq_2f85_2f140_stl/`](../grippers-stl/robotiq_2f85_2f140_stl/) |
| **Open Arm** | Modular Open-Source Parallel Mount | **Available** | [`grippers-stl/open_arm_stl/`](../grippers-stl/open_arm_stl/) |
| **I2RT YAM** | Native Dual M3 Clamp (Wenli Xiao Baseline) | **Available** | [`grippers-stl/enpire_i2rt_yam_stl/`](../grippers-stl/enpire_i2rt_yam_stl/) |
| **ALOHA / Mobile ALOHA** | ViperX Parallel Jaw Carriage | *In Progress* | [`grippers-stl/aloha_stl/`](../grippers-stl/aloha_stl/) |
| **AgileX (Piper)** | Dual Pin + M3 Fastener Slider | *In Progress* | [`grippers-stl/agilex_stl/`](../grippers-stl/agilex_stl/) |
| **Seeed Studio reBot** | AI Arm Parallel Gripper Slider | *In Progress* | [`grippers-stl/seeed_rebot_stl/`](../grippers-stl/seeed_rebot_stl/) |
| **Franka Panda / FR3** | Quick-Mount Dovetail / M4 Slider | *In Progress* | [`grippers-stl/franka_panda_stl/`](../grippers-stl/franka_panda_stl/) |
| **ARX5** | Direct Dual Lug M3 Pattern | *In Progress* | [`grippers-stl/arx5_stl/`](../grippers-stl/arx5_stl/) |
| **ISO 9409-1 (UR / xArm)** | Universal Tool Flange Adapter Plates | *In Progress* | [`grippers-stl/iso_flange_adapters_stl/`](../grippers-stl/iso_flange_adapters_stl/) |

*Status: Available (Production-ready STL models available) | In Progress (Community Contributions Welcome)*

---

## Contributing New Arm Adapters

To add an adapter for an unlisted robot arm or gripper:
1. Export high-resolution binary **STL** files into `grippers-stl/<arm_folder>_stl/`.
2. Follow the rules in [CONTRIBUTING.md](../CONTRIBUTING.md).
3. Open a Pull Request referencing the robot arm platform!

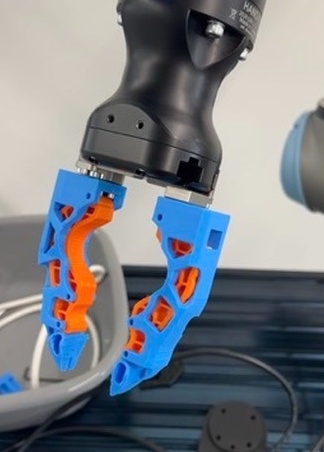
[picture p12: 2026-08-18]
docs/images/hand_e_enpire_fingers_detail.jpg

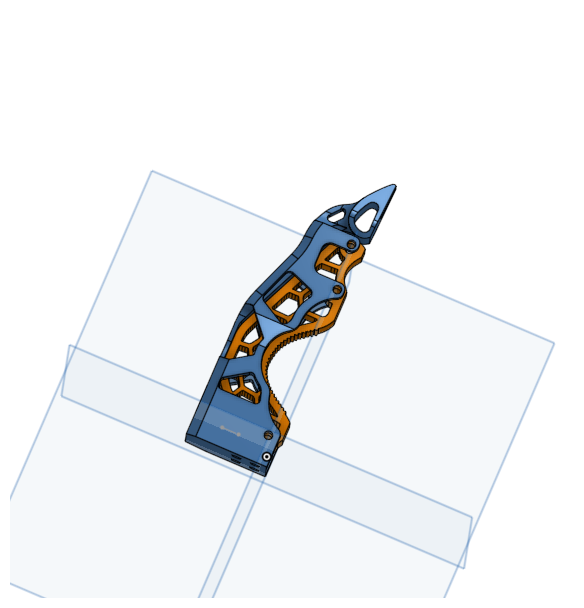
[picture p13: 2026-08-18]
docs/images/enpire_finger_model_render.png

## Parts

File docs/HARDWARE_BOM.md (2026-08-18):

# Hardware Bill of Materials (BOM)

This document specifies all mechanical hardware, fasteners, inserts, casting materials, and filaments required to assemble the **ENPIRE Gripper** and its various robot arm adapter variants.

---

## 1. Fasteners & Mechanical Hardware

| Component | Specification | Quantity (per arm) | Target Application | Recommended Torque |
| :--- | :--- | :---: | :--- | :--- |
| **M3 Socket Head Cap Screws** | M3 × 12mm (DIN 912 / ISO 4762, Grade 12.9) | 4 | Base mounting for I2RT YAM / Piper fingers | 1.2 Nm |
| **M3 Socket Head Cap Screws** | M3 × 16mm (DIN 912) | 2 | Clamp retention for extended fingers | 1.2 Nm |
| **M3 Button Head Screws** | M3 × 8mm (ISO 7380) | 4 | Low-profile slider retention | 0.8 Nm |
| **M4 Socket Head Cap Screws** | M4 × 16mm (DIN 912, Grade 12.9) | 4 | Robotiq 2F-85 / 2F-140 bracket adapter | 2.5 Nm |
| **M6 Socket Head Cap Screws** | M6 × 16mm (DIN 912) | 4 | ISO 9409-1-50-4-M6 Tool Flange (UR, xArm) | 8.0 Nm |
| **M5 Socket Head Cap Screws** | M5 × 12mm (DIN 912) | 4 | ISO 9409-1-31.5-4-M5 Compact Tool Flange | 4.5 Nm |
| **M3 Threaded Heat-Set Inserts** | M3 × 4.0mm (OD 4.6mm, Brass tapered) | 4–8 | Finger mounting blocks & slider brackets | Heat press at 220°C–240°C |
| **M4 Threaded Heat-Set Inserts** | M4 × 5.0mm (OD 6.0mm, Brass tapered) | 4 | Robotiq adapter bracket base | Heat press at 230°C–250°C |

---

## 2. 3D Printing Materials

| Material Type | Recommended Brand / Grade | Color | Target Parts | Key Mechanical Properties |
| :--- | :--- | :--- | :--- | :--- |
| **PETG-CF / PLA-CF** | Bambu Lab PETG-CF / Polymaker PolyMide | Matte Black | Structural finger beams, adapter brackets | High stiffness, low creep, sharp details |
| **Nylon (PA12-CF)** | Bambu PA-CF / Polymaker PA6-CF | Dark Gray | Heavy-duty industrial finger bodies | Superior impact strength & temperature resistance |
| **TPU (Flexible)** | TPU 95A / TPU 85A (NinjaTek / Overture) | Green / Orange | Snap-in high-friction grip pads | Shore 85A–95A, high coefficient of friction ($\mu > 0.8$) |
| **Tough Resin (SLA)** | Formlabs Tough 2000 / Siraya Tech Blu | Translucent / Gray | Precision pinch fingers & micro-clamps | High dimensional accuracy ($\pm 0.05\text{ mm}$) |

---

## 3. Silicone Casting Supplies (Optional for Soft High-Grip Tips)

For handling glossy, wet, or delicate objects with maximum friction:
- **Silicone Compound**: Smooth-On *Dragon Skin™ 20* or *Ecoflex™ 00-30* (1:1 mix ratio by weight)
- **Mold Release Agent**: Smooth-On *Universal Mold Release* or Mann *Ease Release 200*
- **Mixing / Degassing Equipment**: Disposable mixing cups, stir sticks, and optional vacuum degassing chamber (recommended to remove micro-bubbles)
- **Silicone Pigment**: Silc Pig™ (Electric Green or Signal Red)

---

## 4. Tools Required for Assembly

- 2.0mm & 2.5mm Metric Hex (Allen) Keys / Precision bit driver
- 3.0mm & 5.0mm Hex Keys (for M4 and M6 bolts)
- Soldering iron with M3/M4 conical heat-set insert installation tip
- Digital calipers (0.01mm resolution)
- Loctite 243 (Medium-strength blue threadlocker)

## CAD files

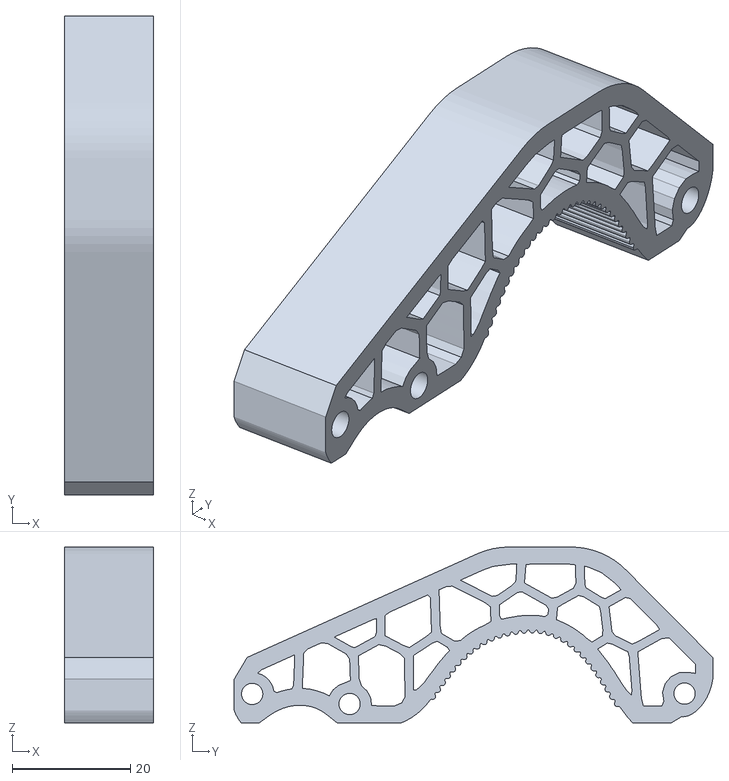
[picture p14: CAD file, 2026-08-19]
grippers-stl/enpire_i2rt_yam_stl/I2RT_UCG_Soft.stl
15.0 x 81.0 x 29.8

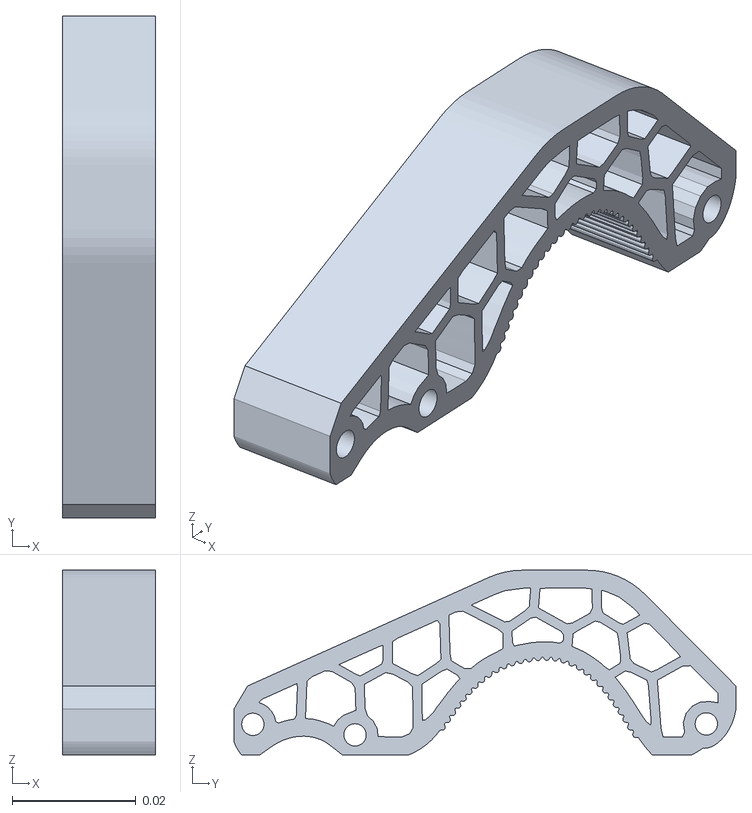
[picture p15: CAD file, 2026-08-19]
grippers-stl/hand_e_stl/Robotiq_UCG_Soft_Hand_E.stl
0.015 x 0.081 x 0.0298

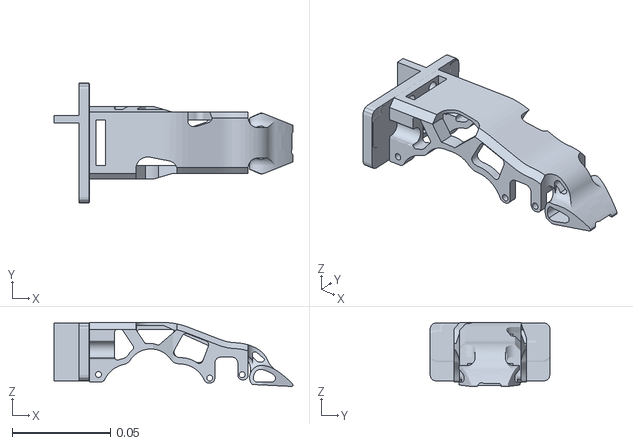
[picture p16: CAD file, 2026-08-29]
grippers-stl/open_arm_stl/OpenArm_UCG_left_hard.stl
0.122 x 0.061 x 0.0326

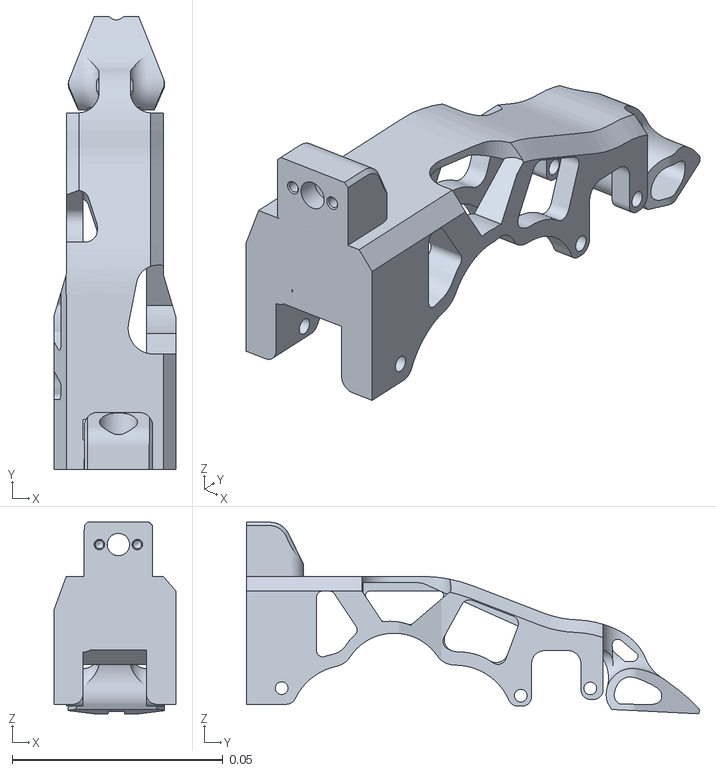
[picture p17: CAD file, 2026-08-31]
grippers-stl/robotiq_2f85_2f140_stl/Robotiq_2F-140-UCG_Hard.stl
0.0289 x 0.107 x 0.0454

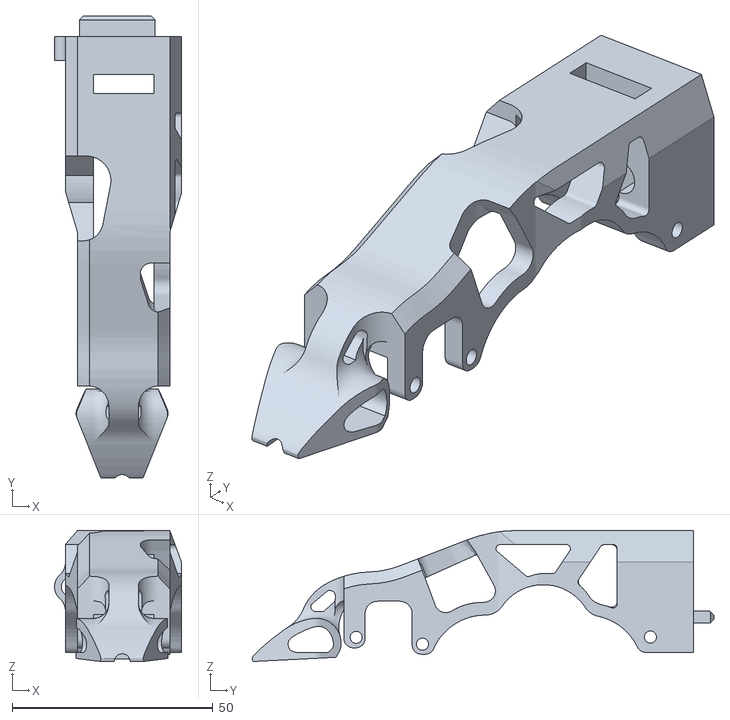
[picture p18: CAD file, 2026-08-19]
grippers-stl/enpire_i2rt_yam_stl/i2rt_UCG_Hard.stl
31.6 x 114.9 x 32.6

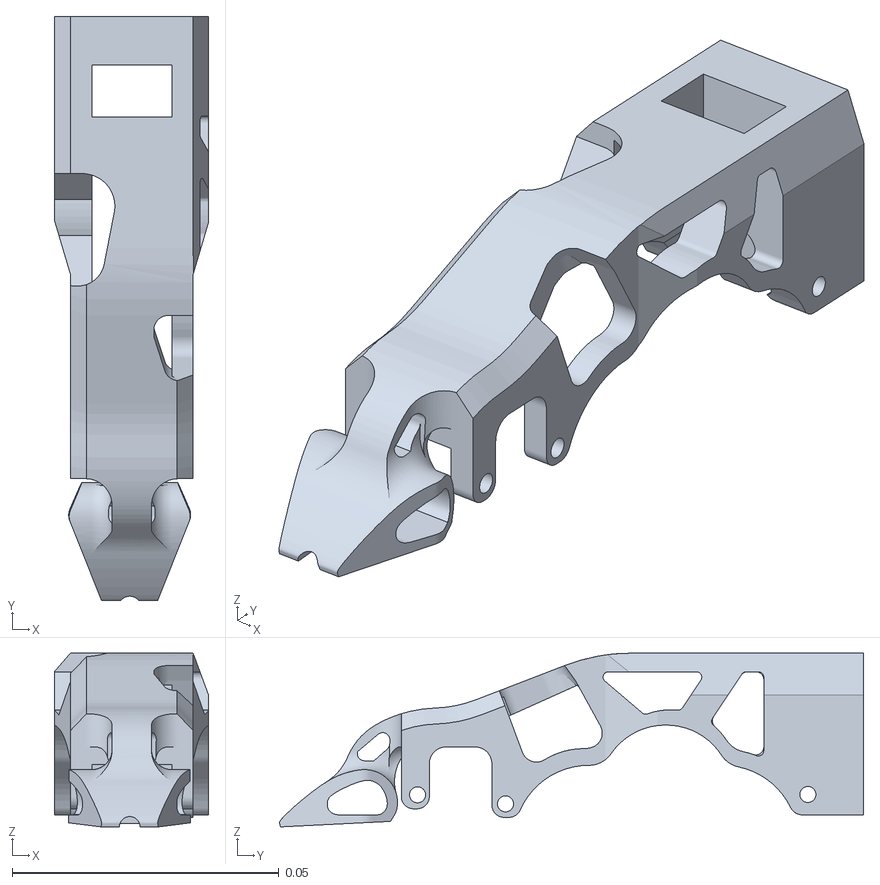
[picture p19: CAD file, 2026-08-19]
grippers-stl/hand_e_stl/Robotiq_UCG_Hard_Hand_E.stl
0.0289 x 0.11 x 0.0326

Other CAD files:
grippers-stl/open_arm_stl/open-arm_enpire_left-jaw.stl
grippers-stl/robotiq_2f85_2f140_stl/Robotiq_2F-140-UCG_soft.stl

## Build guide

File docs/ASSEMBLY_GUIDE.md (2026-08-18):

# Assembly & Installation Guide

This guide covers physical hardware assembly, fastening, and gripper mounting for the **Open-ENPIRE-Gripper** family.

---

## 1. Required Hardware & Tools

* **Fasteners**: Metric socket head cap screws (Grade 12.9) — standard M3/M4 depending on arm bracket.
* **Heat-Set Inserts**: M3 / M4 brass threaded inserts.
* **Chemicals**: Medium-strength blue threadlocker (Loctite 243).
* **Tools**:
  * Metric hex key set (2.0 mm, 2.5 mm, 3.0 mm)
  * Soldering iron with flat/conical tip (for heat-set insert press-in)
  * Calipers (0.01 mm precision)
* **3D-Printed Parts**: 3D-printed finger components from [`grippers-stl/`](../grippers-stl/).

---

## 2. Installation Steps

### Step 1: Heat-Set Insert Installation
1. Heat soldering iron to **230°C** for PETG/PLA or **275°C** for PA-CF.
2. Place the M3/M4 insert straight onto the mounting hole.
3. Gently press downward with the iron tip until the insert sits perfectly flush with the plastic face.
4. Allow 60 seconds to cool and lock into place.

### Step 2: Finger Mounting to Gripper Chassis
1. Align the finger adapter mounting counterbores with the gripper slider brackets.
2. Apply a drop of medium threadlocker to the screw threads.
3. Torque fasteners evenly until firm (do not overtighten into plastic).

### Step 3: Stroke & Clearance Check
1. Manually command the gripper from fully open (0 mm) to fully closed (50 mm).
2. Verify that both fingertips meet symmetrically along the center line without binding or rubbing against the actuator body.

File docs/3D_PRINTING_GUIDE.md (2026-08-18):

# 3D Printing & Fabrication Guide

This guide details the recommended materials, slicing profiles, and hardware assembly steps for manufacturing the **Open-ENPIRE-Gripper** finger adapters.

All components have been printed, fitted, and tested on a **Bambu Lab P1S** using **Bambu Studio / OrcaSlicer**.

---

## 1. Material Recommendations

### A. Rigid Structural Outer Frame
* **Primary Recommendation**: **PETG-CF** or **PLA-CF** (Carbon Fiber reinforced).
* **High-End Industrial Option**: **PA12-CF (Nylon-CF)**.
* **Why CF Filament?**: Carbon fiber infill significantly increases tensile modulus, prevents bending under 130 N clamping forces, and provides clean dimensional accuracy for M3/M4 bolt counterbores.

### B. High-Friction Compliant Grip Core
* **Primary Recommendation**: **TPU 85A** or **TPU 95A** (Thermoplastic Polyurethane).
* **Why TPU?**: Offers exceptional surface friction ($\mu > 0.8$) and elasticity, allowing the fingertips to conform passively around micro-pins, deformable cables, and delicate PCBs without marring surfaces.

---

## 2. Tested Slicer Profiles (Bambu Lab P1S)

| Parameter | Rigid Frame (PETG-CF / PA-CF) | Compliant Grip Core (TPU 85A/95A) |
| :--- | :--- | :--- |
| **Tested Machine** | **Bambu Lab P1S** | **Bambu Lab P1S** |
| **Layer Height** | **0.16 mm** | **0.16 mm – 0.20 mm** |
| **Wall Loops / Perimeters** | **5 – 6 walls** (Critical for strength) | **4 walls** |
| **Top / Bottom Solid Layers** | **5 Top, 5 Bottom** | **4 Top, 4 Bottom** |
| **Infill Pattern** | **Gyroid (50% – 60%)** | **Gyroid (30% – 40%)** |
| **Nozzle Temperature** | 255°C (PETG-CF) / 285°C (PA-CF) | 225°C – 235°C (TPU) |
| **Bed Temperature** | 70°C – 80°C (Textured PEI Plate) | 45°C – 55°C (Engineering Plate) |
| **Printing Speed** | 80 – 160 mm/s | 20 – 35 mm/s |
| **Supports** | Tree Auto (40° threshold, 0.2mm Top-Z) | None needed |

---

## 3. Infill Geometry & Support Details

### Infill Pattern
* **Gyroid**: Strongly recommended over Grid or Triangles. Gyroid distributes compression and shear stresses isotropically in 3D, preventing internal shear fractures when clamping under high motor current.

### Support Settings (Bambu Studio / OrcaSlicer)
* **Support Type**: Tree (Auto) / Tree Slim
* **Threshold Angle**: 35° – 45°
* **Top Z Distance**: **0.20 mm** (enables clean interface release with zero surface scarring)
* **Bottom Z Distance**: 0.20 mm
* **Support Wall Loops**: 1

---

## 4. Hardware Assembly Tips

1. **Heat-Set Threaded Inserts**:
   * Set your soldering iron to **230°C** for PETG/PLA or **275°C** for PA-CF.
   * Press M3 or M4 brass inserts straight and flush with the plastic face.
2. **Fastener Torquing & Threadlocker**:
   * Use Grade 12.9 M3/M4 socket head cap screws.
   * Apply medium blue threadlocker (Loctite 243) to prevent bolts from loosening under high-speed robotic cycles.

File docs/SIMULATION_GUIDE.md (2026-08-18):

# Simulation Guide (NVIDIA Isaac Sim, MuJoCo, ROS 2)

This guide covers importing and controlling the **ENPIRE Gripper** in robotics simulation environments.

---

## 1. NVIDIA Isaac Sim & Isaac Lab (Omniverse)

The ENPIRE gripper URDFs are directly compatible with NVIDIA Isaac Sim / Isaac Lab:

### Loading the URDF in Isaac Sim
1. In Isaac Sim, navigate to `Isaac Utils` -> `Workflows` -> `URDF Importer`.
2. Select `urdf/enpire_yam_gripper.urdf` (or your arm of choice).
3. Set the following import options:
   - **Fix Base Link**: Checked (or attach to robot arm tool link).
   - **Self Collision**: Enabled.
   - **Convex Decomposition**: Enabled (V-HACD algorithm).
   - **Drive Type**: `Position` or `Force` (Gain: $k_p=1000$, $k_d=50$).
4. Click **Import**.

### Isaac Lab Simulation Python Snippet
```python
from omni.isaac.lab.actuators import ImplicitActuatorCfg
from omni.isaac.lab.assets import ArticulationCfg

ENPIRE_GRIPPER_CFG = ArticulationCfg(
    prim_path="{ENV_REGEX_NS}/Robot/enpire_gripper",
    spawn=None,
    init_state=ArticulationCfg.InitialStateCfg(
        pos=(0.0, 0.0, 0.0),
        joint_pos={"left_finger_joint": 0.04, "right_finger_joint": 0.04},
    ),
    actuators={
        "fingers": ImplicitActuatorCfg(
            joint_names_expr=[".*_finger_joint"],
            effort_limit=50.0,
            velocity_limit=0.2,
            stiffness=1000.0,
            damping=50.0,
        ),
    },
)
```

---

## 2. MuJoCo Simulation

To import into MuJoCo, convert the URDF using the built-in compiler:
```bash
# Convert URDF to MJCF XML
python3 -c "import mujoco; m = mujoco.MjModel.from_xml_path('urdf/enpire_yam_gripper.urdf'); print('Loaded successfully in MuJoCo! NV:', m.nv)"
```

---

## 3. ROS 2 & MoveIt 2 Integration

Include the parameterized Xacro macro inside your robot's main URDF/Xacro description:

```xml
<xacro:include filename="$(find enpire_gripper)/urdf/enpire_gripper.urdf.xacro" />

<!-- Attach ENPIRE gripper to robot wrist / tool flange -->
<xacro:enpire_gripper prefix="gripper_" parent="wrist_3_link" stroke="0.08">
  <origin xyz="0 0 0" rpy="0 0 0" />
</xacro:enpire_gripper>
```

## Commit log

2026-08-18 feat: initialize open-source ENPIRE multi-arm gripper repository
    [arx5_enpire_finger_heavy_duty.stl, arx5_enpire_finger_left.stl, arx5_enpire_finger_right.stl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]
2026-08-18 docs: update repository URLs to Open-ENPIRE-Gripper-nvidia
2026-08-18 feat: credit Wenli Xiao MakerWorld original, highlight Hand-E adapter and NVIDIA GEAR research, clean CAD/mesh folders
    [arx5_enpire_finger_heavy_duty.stl, arx5_enpire_finger_left.stl, arx5_enpire_finger_right.stl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]
2026-08-18 docs: enrich story and vision on democratizing ENPIRE gripper for generalist robot arms
2026-08-18 docs: rewrite README with HandUMI-style storytelling, direct technical hook, and Jim Fan tags
2026-08-18 feat: replace SO-100 with ALOHA, Open Arm, AgileX, and Seeed Studio reBot adapters
2026-08-18 docs: remove CAD references, standardize on STL models, and add comprehensive Rules for Contributing
2026-08-18 docs: simplify README with ENPIRE video, Hand-E design diagram, compatibility heatmap, and best printing instructions
2026-08-18 feat: delete pyproject/requirements/gitignore, adopt _stl folder convention, and add README for each arm
2026-08-18 docs: add WIP status and community PR invitations to all pending arm directories
2026-08-18 feat: add side-by-side animated ENPIRE research video and Robotiq Hand-E gripper comparison
2026-08-18 feat: add URDF generator from STL, detailed 3D printing guide, dual citations, finger render, and balanced video dimensions
2026-08-18 docs: add comprehensive badges for NVIDIA, Isaac Sim, MakerWorld, simulation, and 3D printing
2026-08-18 docs: remove robot arm list from README header for a cleaner top section
2026-08-18 docs: keep only License, NVIDIA, Jim Fan, and Hardware Open Source badges
2026-08-18 feat: add original NVIDIA ENPIRE I2RT YAM gripper photo to Purpose section and YAM directory
2026-08-18 docs: detail Bambu Lab P1S tested print profiles, Gyroid infill, and Tree support settings
2026-08-18 feat: rename stl/ directory to grippers-stl/ and update all documentation and script references
2026-08-18 feat: place Original NVIDIA ENPIRE YAM gripper and Generalist AI bimanual manipulation images side-by-side
2026-08-18 docs: adopt Universal Compliant Gripper (UCG) terminology and detail robot learning models (pi_0, GR00T, Diffusion Policy, ACT, OpenVLA)
2026-08-18 feat: add production-ready Robotiq Hand-E left and right ENPIRE finger STL models
    [hand_e_enpire_finger_left.stl, hand_e_enpire_finger_right.stl]
2026-08-19 feat: add Robotiq logo, OEM standard Hand-E, and mounted UCG gripper comparison to READMEs
2026-08-19 style: balance OEM Standard Hand-E and mounted UCG gripper images to matching 480x720 dimensions
2026-08-19 style: frame and resize OEM standard and custom UCG images to exact identical 500x650 box
2026-08-19 Update README to remove finger variant descriptions
    Removed descriptions for grooved and pinch finger variants.
2026-08-24 feat(cad): add Open-ENPIRE left jaw STL for open-arm gripper
    Add open-arm_enpire_left-jaw.stl CAD mesh for the left gripper jaw assembly under grippers-stl/open_arm_stl.
    [open-arm_enpire_left-jaw.stl]
2026-08-31 fix(cad): fix double stl extension and make validation/urdf scripts zero-dependency
    [Robotiq_2F-140-UCG_Hard.stl]
2026-08-31 docs(sync): update individual gripper READMEs, root README, and compatibility matrix for Robotiq 2F-140, OpenArm, and I2RT YAM
2026-08-31 Rename ENPIRE_gripper_finger - soft-gripper-body (1).stl to Robotiq_2F-140-UCG_soft.stl
    [Robotiq_2F-140-UCG_soft.stl]
2026-08-31 feat(renders): add zero-dependency 3D STL renderer and embed high-res CAD renders in individual and main READMEs
2026-08-31 docs(robotiq): add Robotiq_2F-140-UCG_soft.stl to 2F README and root model catalog

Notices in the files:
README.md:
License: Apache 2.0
